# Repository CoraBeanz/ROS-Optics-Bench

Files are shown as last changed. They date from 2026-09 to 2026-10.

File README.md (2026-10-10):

<p align="center">
  Self-Aligning Laser-to-Fiber Bench. Seen from above, a 635 nm laser beam passes an aperture, two polarizers and a beamsplitter, folds off two motorized mirrors, M1 and M2, and is focused into a single-mode fiber. M1 gets knocked, the focused spot slides off the fiber's core and the coupling drops t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
</p>

<h3 align="center">A mostly 3D-printed optical bench that couples a 635 nm laser into an optical fiber by itself. Knock a mirror out of line and four stepper-driven adjusters steer the beam back to peak coupling, with no hands on the knobs.</h3>

<p align="center">
  
  
  
  
  
  
  
  
</p>

<p align="center">
  <a href="#how-it-works"><b>How it works</b></a> ·
  <a href="#the-bench"><b>The bench</b></a> ·
  <a href="#optical-path"><b>Optical path</b></a> ·
  <a href="#auto-align"><b>Auto-align</b></a> ·
  <a href="#electronics"><b>Electronics</b></a> ·
  <a href="#software"><b>Software</b></a> ·
  <a href="#roadmap"><b>Roadmap</b></a> ·
  <a href="docs/bom/README.md"><b>Parts list</b></a>
</p>

## How it works

Getting a laser into a single-mode fiber means landing a focused spot on a core a few microns across, at the right angle. By hand that takes two kinematic mirrors, four knobs and a lot of patience. Here a NEMA 8 stepper turns each knob, and two photodiodes tell the motors how close they are.

| 1 · Score the coupling | 2 · Find the light | 3 · Steer and walk |
|---|---|---|
| A beamsplitter sends part of the laser to a reference photodiode, and the fiber's output lands on a second one. Their ratio is the score, so laser flicker cancels out. | After a knock the spot has usually left the core and the output reads nothing. M2 steps the spot outward in a square spiral until the output photodiode sees light again. | M2 alone moves the spot across the core. M1 with a matched, opposite M2 move changes only the angle. Alternating the two climbs the long, thin peak that one-knob-at-a-time adjusting stalls on. |

## The bench

<p align="center">
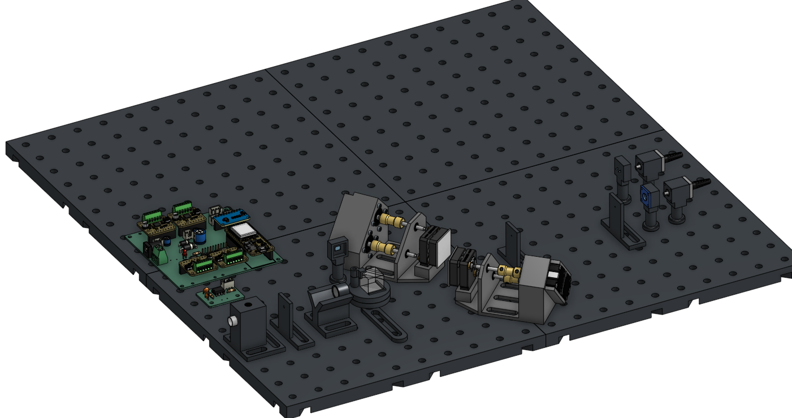
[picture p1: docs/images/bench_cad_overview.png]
Onshape render of the whole bench on four printed breadboard tiles: the control board at the back left, the laser, aperture, polarizer and beamsplitter in front, the two motor-mirror assemblies in the middle, and the lens and fiber mounts at the right.
  
</p>

<table>
  <tr>
    <td width="50%" valign="top">
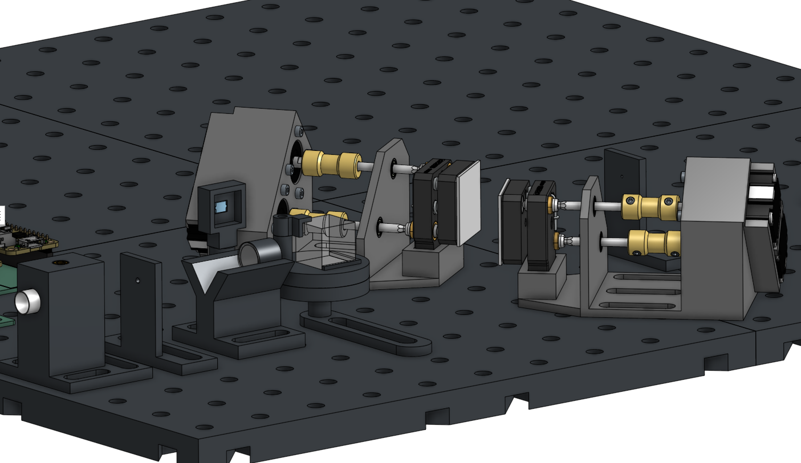
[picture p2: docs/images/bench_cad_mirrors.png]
Close-up render of the laser, polarizer and beamsplitter, then M1 and M2, each with two NEMA 8 motors turning its adjusters through brass couplers and hex rods.
      
      <br><sub>Laser, polarizer and beamsplitter, then M1 and M2, each with two NEMA 8 motors turning its adjusters through brass couplers and hex rods.</sub>
    </td>
    <td valign="top">

**Light.** A 635 nm Quarton laser module under 1 mW, trimmed by a 2 mm printed aperture and dimmed by two crossed polarizers.

**Steering.** Two 1 in mirrors in Thorlabs KMS-style kinematic mounts. A NEMA 8 stepper turns each 100 TPI adjuster through a brass coupler and a 2 mm hex rod: four motorized axes, 79 nm of screw travel per microstep.

**Focus.** An f = 8 mm asphere on a micrometer stage focuses the beam onto a fixed FC bulkhead. The lens moves; the fiber stays put.

**Sensing.** BPW34 photodiodes on MCP6002 transimpedance amps, read by a 16-bit ADS1115.

**Control.** An ESP32 Feather V2 drives four TMC2209s on one UART bus and takes plain-text commands over USB from a desktop test panel or from ROS 2 on a Jetson.

**Base.** Printed breadboard tiles on a 25 mm hole grid, so parts come off and go back in the same place.

  </td>
  </tr>
</table>

The full CAD model is one STEP file exported from Onshape with its subassembly tree, [`cad/assemblies/ros_laser_bench_main_assembly.step`](cad/assemblies/README.md). Every part to buy, print or check is in the [parts list](docs/bom/README.md) (source: `docs/bom/bom.csv`).

## Optical path

<p align="center">
  Top view of the optical path: laser, 2 mm aperture, crossed polarizers and beamsplitter along the bottom, with the reference photodiode on the beamsplitter's side port; M1 turns the beam up to M2, 150 mm away, which sends it along the top through two irises to the f = 8 mm asphere on its stage and 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
</p>

The beam folds in a Z. M1 and M2 sit 150 mm apart, and M2 is 310 mm from the lens, so tilting the two mirrors together can set both where the beam crosses the lens and the angle it arrives at, and through them where the focused spot lands on the fiber face and the angle it enters at. One microstep tilts a mirror by about 4.6 µrad. One turn of M2's X adjuster moves the spot about 230 µm across the fiber face, and one turn of its Y adjuster about 165 µm, because at a 45° fold a vertical tilt bends the beam by √2 times the tilt instead of twice it.

The 2 mm aperture does mode matching. The laser's 7 x 3 mm beam is much bigger than the single-mode fiber's mode seen at the lens (1.5 mm across), so only its centre can couple. In the bench twin 83% of the light through the aperture couples, against 25% of the whole beam without it. The fiber gets about a quarter of the laser's power either way, but with the aperture the light that could never couple is stopped before the beamsplitter, so the out/ref score at the peak is 0.67 instead of 0.20. In phase 1 the OV9281's bare sensor takes the lens's place, and with the two irises it lets the mirrors put the beam on the lens axis by spot position before the lens and fiber go in.

## Auto-align

<p align="center">
  Coupling over M1X and M2X computed by the bench twin: a long, thin, bright ridge running diagonally. After M1 is knocked 1.2 mrad, a square spiral on M2 finds the light on the ridge, then the steer-and-walk path follows the ridge to 99% of the best, while one motor at a time stalls part-way along i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
</p>

With a single-mode fiber the coupling depends on where the spot lands on the core (set by the beam's angle at the lens) and on the angle it comes in at (set by the beam's offset at the lens). The first is about 25 times more sensitive, and both mirrors change both, so in motor coordinates the peak is a ridge 23 times longer than it is wide, running diagonally across M1 and M2. Turning one knob at a time crawls along it. Auto-align, in the [test panel](#bench-test-panel) and as a [ROS 2 action](#ros-2-on-the-jetson), uses the two moves people use by hand instead:

- **Find.** If the output photodiode sees nothing, M2 steps the spot outward in a square spiral, up to **Search (turns)** either way, until the out/ref ratio clears 2% of its aligned value.
- **Steer.** M2 alone moves the spot across the core: the narrow direction, 25 microsteps to the 1/e point on M2X.
- **Walk.** M1 plus a matched, opposite M2 move keeps the spot where it is and changes only the angle: the wide direction, about 580 microsteps of M1.
- **Repeat** walk and steer on both planes until a sweep gains less than 0.3%. Each line search approaches its points from the same side, so the play in the hex couplings always sits the same way.

The first run on a fiber also measures the walk directions on the real bench, since they depend on motor directions and lever arms. In 100 simulated knocks of 0.3 to 3 mrad, steer and walk brought all 100 back above 99.9% of the best coupling, with a median of 19 s and a worst case of 66 s. One motor at a time got 59 back to 90%. Everything here comes from the [bench twin](#bench-twin-simulator); Auto-align hasn't run on the hardware yet.

## Electronics

| Part | Role |
| --- | --- |
| Adafruit ESP32 Feather V2 | Real-time side: steppers, soft limits, photodiode sampling, laser |
| 4x Adafruit TMC2209 breakout on one UART bus | Stepper drivers: 3200 microsteps per adjuster turn, StealthChop, current set over UART |
| ADS1115 (16-bit ADC) + 2x BPW34 photodiode on an MCP6002 transimpedance amp (47 kΩ) | Reference and output power |
| 12 V supply | Motor power; the Feather runs from USB |
| Jetson (ROS 2) | Camera, optimizer, experiment control |
| Arducam OV9281 (global shutter, UVC) | Bare-sensor beam profiler for phase 1 |

<table>
  <tr>
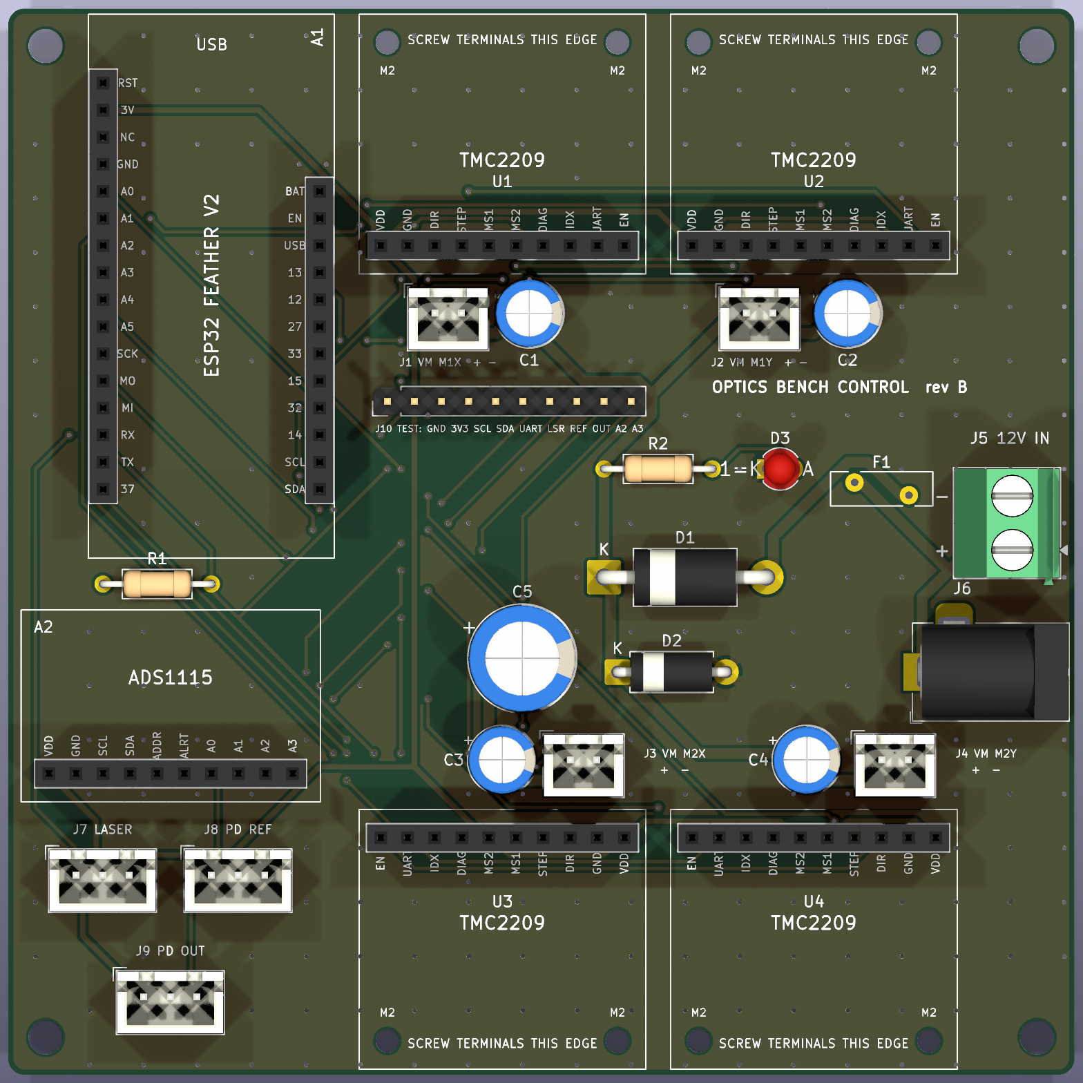
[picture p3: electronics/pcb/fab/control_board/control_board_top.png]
Top render of the control board: sockets for the ESP32 Feather V2, four TMC2209 breakouts with their screw-terminal edges facing out, and the ADS1115; the 12 V input with fuse, diodes and bulk capacitor; JST-XH plugs for the drivers, laser and both photodiodes; and a 10-pin test header.
    <td width="58%"></td>
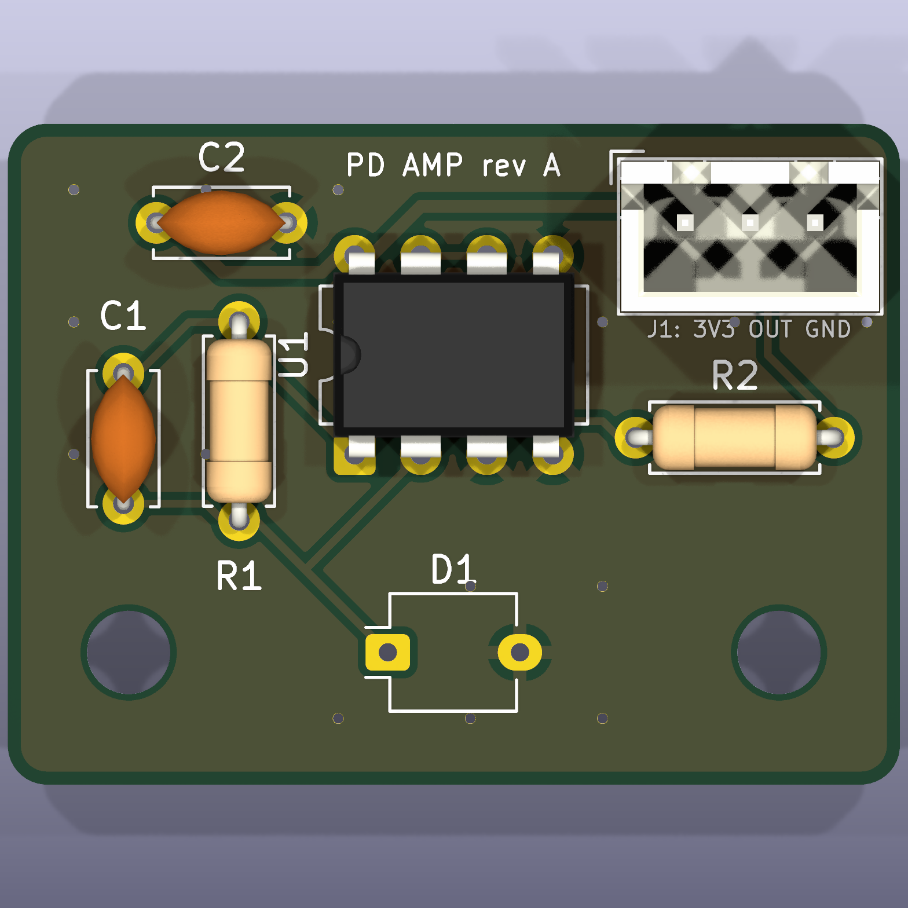
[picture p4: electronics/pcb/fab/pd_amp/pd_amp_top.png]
Top render of the photodiode amp board: the BPW34 footprint, the MCP6002 op-amp, the feedback resistor and capacitor, and a 3-pin JST-XH plug.
    <td width="42%"></td>
  </tr>
  <tr>
    <td><sub>Control board, 100 x 100 mm, two layers. The Feather, the four TMC2209 breakouts and the ADS1115 plug in.</sub></td>
    <td><sub>Photodiode amp, 34 x 25 mm. Build two: reference and output.</sub></td>
  </tr>
</table>

Both boards are KiCad 10 projects generated from Python, all through-hole, with Gerbers ready to order in [electronics/pcb](electronics/pcb/README.md). Every cable on the bench is in [electronics/system_wiring.svg](electronics/system_wiring.svg), and the full pin table is in [electronics/wiring.md](electronics/wiring.md).

## Software

<p align="center">
  Block diagram of the code. The ESP32 firmware drives the four motor drivers, the laser and the ADS1115, and talks plain text over USB serial. bench_link connects either the real ESP32 or the bench twin simulator to two front ends, the PySide6 test panel and the ROS 2 packages on the Jetson, which b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
</p>

Where each piece lives, and how far it has been run:

| Module | What it does | Run so far |
| --- | --- | --- |
| [`firmware/optics_bench`](#building-the-firmware) | Arduino IDE sketch for the ESP32: four axes with soft limits and positions kept in flash, auto-ranging photodiode sampling, the laser, and the serial protocol | On the bench: laser, all four motors and both photodiodes |
| [`tools/test_gui.py`](#bench-test-panel) | Dark-mode PySide6 test panel: jog, go-to, photodiode readout and plots, CSV logging and Auto-align; `--sim` runs it on the bench twin | On the bench; Auto-align on the simulator only |
| [`tools/bench_twin`](#bench-twin-simulator) | Physical model of the bench and the Aligner both front ends run; `tools/twin.py` runs trials and draws figures | 14 unit tests |
| [`host/ros2_ws`](#ros-2-on-the-jetson) | ROS 2 Humble packages for the Jetson: the bench as topics, services and actions, Align as an action, and a beam-spot node for the OV9281 | Against the simulator on Humble |

### Building the firmware

1. In the Arduino IDE, install the ESP32 boards package (Boards Manager, "esp32" by Espressif).
2. Install the libraries below with the Library Manager.
3. Open `firmware/optics_bench/optics_bench.ino`.
4. Select your ESP32 board and port, then Upload. Serial Monitor runs at 115200 baud with newline line endings.

Code in `src/` is compiled with the sketch automatically. Record any library added through the Library Manager here so the build can be reproduced.

| Library | Version | Used for |
| --- | --- | --- |
| TMCStepper (teemuatlut) | 0.7.3 | TMC2209 register setup over UART |
| AccelStepper (Mike McCauley) | 1.64 | Ramped STEP/DIR motion |
| Adafruit ADS1X15 | 2.6.2 | ADS1115 photodiode ADC over I2C (pulls in Adafruit BusIO) |

The firmware was last built with the esp32 boards package 3.3.7.

Every pin is set in `firmware/optics_bench/config.h`. The wiring diagram and full pin table for the Feather ESP32 V2, the four Adafruit TMC2209 breakouts, the laser, the ADS1115 and the two photodiode amplifier boards are in [electronics/wiring.md](electronics/wiring.md). The serial protocol is plain text and documented in `firmware/optics_bench/src/comms/protocol.h`, so the Serial Monitor or the Jetson can use the same commands.

### Bench test panel

<p align="center">
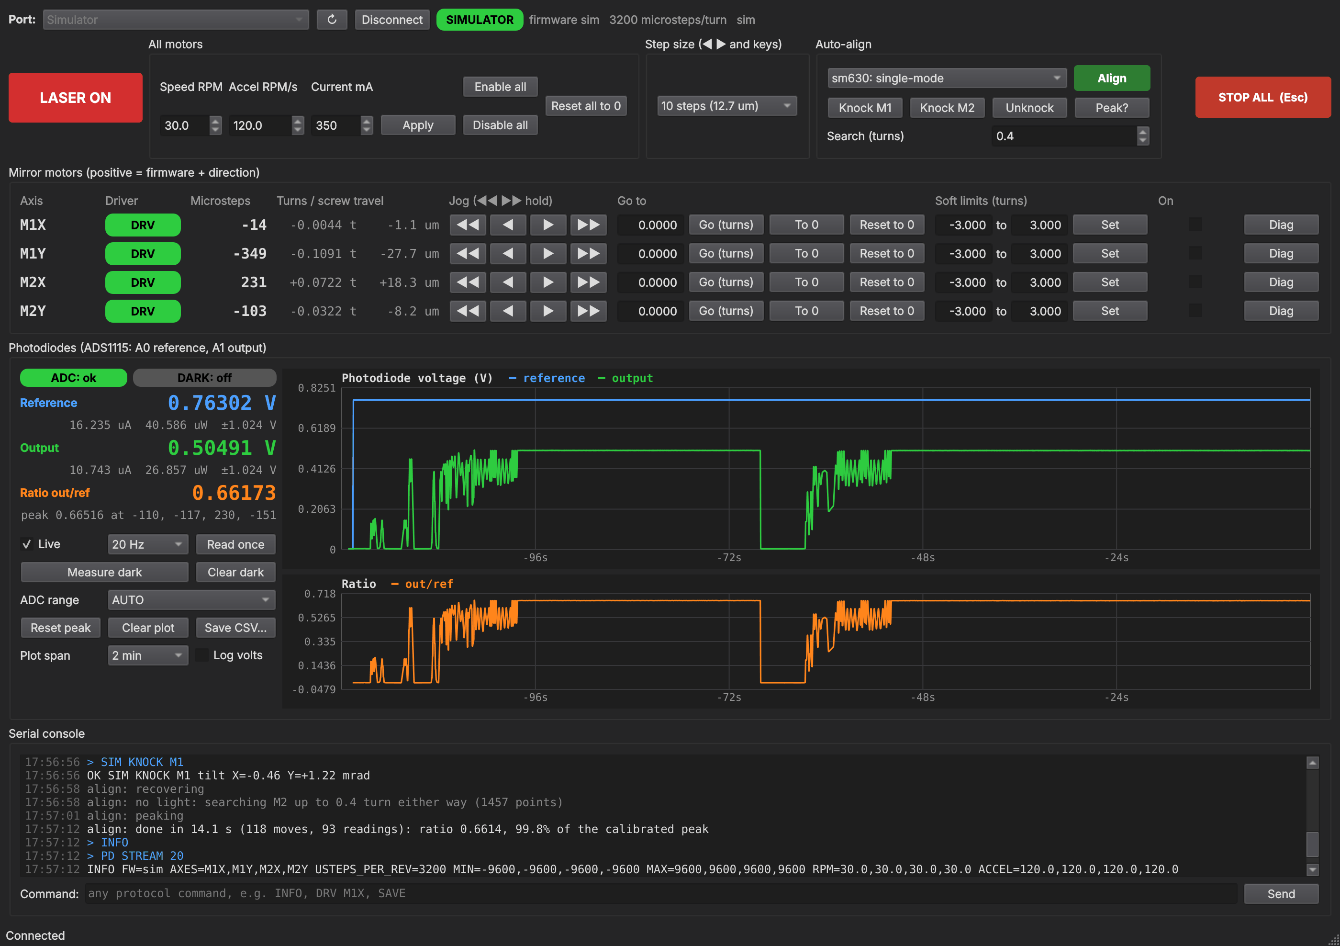
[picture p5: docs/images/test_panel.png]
The test panel connected to the simulator after a knock and an automatic recovery: the four motor rows, the photodiode readout, and plots of the reference and output voltages and their ratio dropping at the knock and climbing back.
  
</p>

`tools/test_gui.py` is a small desktop app for the bench tests: laser on/off, jog, nudge and go-to for the four mirror motors, and live photodiode readings. It is a dark-mode Qt window built on PySide6 (the LGPL Qt binding) and pyserial, both listed in `tools/requirements.txt`.

```
py -3 -m pip install -r tools/requirements.txt
py -3 tools/test_gui.py          # pick the ESP32's COM port, Connect
py -3 tools/test_gui.py --sim    # try it without hardware
```

`py -3` picks the regular Python install on Windows; a bare `python` can resolve to another bundled interpreter such as KiCad's.

- **Positions** are in microsteps, 3200 per adjuster turn. One turn of a 100 TPI adjuster is 254 um, so a full step is about 1.3 um of screw travel.
- **Zero and soft limits.** "Reset to 0" on a motor's row calls its current knob position zero without moving it, and "Reset all to 0" does all four. Use them whenever the stored position has stopped matching reality, for example after turning an adjuster by hand. The soft limits (default -3 to +3 turns, adjustable up to +-8) stay relative to zero, because the hex bit only has about 4 turns of engagement one way. Positions and limits are saved to flash and survive a power cycle. If power drops mid-move, the panel warns that positions may be off until you press "Reset all to 0" (zeroing the motors one at a time doesn't clear it).
- **Coil release.** A motor is powered only while it moves: it is released 0.5 s after it stops, so the motors stay cool between moves, and the non-back-driving adjuster screws hold the mirror. The **On** box shows whether a motor is powered; ticking it holds that motor powered until you untick it. `AUTO_RELEASE` in `config.h` turns this off.
- **Hold-to-jog** (the double arrows) keeps a motor running while the button is held. The firmware stops it by itself if the panel stops refreshing the jog, so a crashed GUI can't run a motor to its limit.
- **Keys:** arrows move M1 (Left/Right = M1X, Down/Up = M1Y), A/D and S/W move M2X and M2Y by the selected step, L toggles the laser, Esc stops everything.
- **Diag** shows the TMC2209 status (current, StealthChop, overtemperature, short and open-load flags). A driver that doesn't answer on the UART shows a red dot and refuses to move.
- **Auto-align.** Pick the fiber on the bench and press **Align**. It finds the light, then peaks the out/ref ratio by steering with M2 and walking M1 and M2 together (see [Auto-align](#auto-align)). The first run after connecting or switching fiber also measures the walk directions, so start it near the peak; the panel keeps them until it disconnects. Later runs recover from wherever the beam is, for example after a knock. If there is no light on the output photodiode, it first searches with M2 up to **Search (turns)** either way (default 0.4 turn: about ±90 µm across the fiber face and ±65 µm up and down; one turn of M2X moves the spot about 230 µm, one turn of M2Y about 165 µm). The search covers a square, so its time grows with the square of that number, and the log says how many points it will visit. Soft limits still stop any move that would pass them. **Stop** or Esc ends it. It uses the same serial commands as the rest of the panel, but it has only been run against the simulator so far.
- **Photodiodes.** Tick **Live** to stream the reference and output photodiode voltages (5 to 50 readings a second, each the average of all ADC samples since the last one). The panel shows each voltage with its photocurrent and optical power, the output/reference ratio with the best ratio seen and the motor positions where it happened, and a rolling plot (log scale optional). **Measure dark** switches the laser off briefly, records the offsets and subtracts them from then on. **ADC range** fixes the ADS1115 gain instead of auto-ranging, and **Save CSV** writes up to the last 30,000 readings (10 minutes at 50 a second).
- **Simulator.** `--sim` (or the Simulator port) runs the bench twin behind the same serial commands: the photodiodes read what the modelled optics couple into the chosen fiber, with the best position hidden a little way from zero. **Knock M1** and **Knock M2** tilt a mirror by 0.5 to 2 mrad as if bumped, **Unknock** takes the knocks out, and **Peak?** shows where the best position is. Knock, then Align, to watch it recover. The same commands work from the console as `SIM KNOCK M1 [mrad]`, `SIM PEAK`, `SIM FIBER sm630` and `SIM RESET`.

#### First power-up checklist

1. Flash the firmware and connect. A driver whose 12 V supply is off doesn't answer on the UART, so it shows a red dot, and a move on that axis is refused with "driver offline".
2. With the 12 V supply on, send `REPROBE ALL` (or just move the axis, which retries). The dots should go green, and the REPROBE reply should end in `slots=ok` (the connection bar picks it up on the next `INFO`).
3. Take the hex bits out of the adjusters and nudge each motor by 1/4 turn to check which way positive turns. Flip it with `invert` in `config.h` if needed.
4. Refit the bits, press "Reset all to 0", and start aligning.
5. With the ADS1115 and photodiode boards connected, the photodiode panel should show `ADC: ok`. Cover each diode and shine a light on it to check its channel, then press **Measure dark** with the room lit as it will be during runs.

### Bench twin (simulator)

`tools/bench_twin` is a small physical model of the bench, used to size and test the alignment routine before the hardware can. It models:

- **Optics:** the 7 x 3 mm laser beam cut by the 2 mm aperture, the two mirrors 150 mm apart, iris 2 at 3 mm, and the f = 8 mm lens. Single-mode coupling is the overlap of the laser field with the fiber mode, including the aperture's hard edge. Multimode coupling is the share of the focused spot that the core accepts.
- **Motors:** 100 TPI adjusters on a 17.3 mm lever and a little play in each hex coupling. The randomized benches the simulator and the trials use also add a little crosstalk between each mount's two axes.
- **Photodiodes:** the reference and output photodiodes through the ADS1115, with noise and dark offsets.
- **Knocks:** a bumped mirror mount tilts by an amount the motors don't know about.

```
py -3 tools/twin.py                       key numbers (--fiber sm630, mm50 or smf28)
py -3 tools/twin.py ceiling               best coupling vs aperture size and lens focal length
py -3 tools/twin.py trials -n 100 --compare   knock a mirror and recover, 100 times, both methods
py -3 tools/twin.py landscape             redraws docs/images/twin_landscape.png (needs matplotlib)
py -3 -m unittest discover tools/tests
```

What it says so far, for the single-mode fiber:

- **The peak is narrow and diagonal.** Moving M2X alone, coupling falls to 1/e within 25 microsteps (1.5 full steps). Moving M1 and M2 together the opposite way ("walking"), it stays up for about 580 microsteps. So in motor coordinates the peak is a long, thin ridge, 23 times longer than it is wide, running diagonally across M1 and M2. Adjusting one motor at a time stalls part-way along it.
- **Recovery.** In 100 simulated knocks of 0.3 to 3 mrad on a random mirror, steer and walk got all 100 back above 99.9% of the best coupling, with a median of 19 s and a worst case of 66 s (at 60 RPM and 600 RPM/s). One motor at a time got 59 of 100 back to 90%, and its worst case ended at 41%. Most of the time goes into finding the light again. Knocks of M1 above about 5 mrad can defeat the search even though M2 could still put the spot back on the core: the beam then crosses the lens about 1.5 mm off axis and enters the fiber too steeply, so M2 alone brings back under 3% of the peak and the spiral never sees light (7 of the 48 M1 knocks in a run of 100 knocks of 3 to 6 mrad). A larger **Search (turns)** doesn't help these.
- **The 2 mm aperture is close to ideal for coupling efficiency.** With the f = 8 mm lens, 83% of the light that gets through it can be coupled. The best combination tried reaches 86% (a 2.5 mm aperture with f = 11 mm), and 2 mm with f = 9 mm gets 85%. Without the aperture only 25% couples, because the 7 x 3 mm beam is much bigger than the fiber mode seen at the lens (1.5 mm). The aperture passes only 30% of the beam, so the fiber gets about a quarter of the laser's power either way; what it changes is the out/ref ratio at the peak, 0.67 instead of 0.20, since the reference photodiode sits after it.
- **The play in the hex couplings matters.** One degree of play is about 9 microsteps, a third of the single-mode peak's width. Each line search in the routine therefore approaches its points from one side.

The numbers rest on estimates to replace with bench measurements, all set in `tools/bench_twin/bench.py` and `optics.py`:

| Estimate | Value used | How to measure |
| --- | --- | --- |
| Adjuster lever arm | 17.3 mm (from the 24.5 mm motor spacing) | Scan M2X across the peak; the width scales with it |
| Play per hex coupling | 1 degree (9 microsteps) | Hysteresis test: approach the same point from both sides |
| Laser beam | 7 x 3 mm across (taken as the 1/e^2 width) | Camera or knife edge |
| Fiber mode | 4.2 um across (630HP) | Datasheet |
| Lens clear aperture | 5 mm | The lens listing |
| Beamsplitter, laser power, polarizer setting | 50/50, 0.9 mW, 30% | Photodiode volts |

The banner at the top of this page replays one of these runs: M1 knocked 1.5 mrad on the single-mode fiber, recovered in 17 s. The figures are drawn by the scripts in [`docs/images/src`](docs/images/src/common.py); the banner and the Auto-align figure run the twin to get their numbers.

### ROS 2 on the Jetson

`host/ros2_ws` holds ROS 2 Humble packages for the Jetson: a driver node that puts the ESP32 (or the simulator) on ROS topics, services and actions, with Align as an action; a node that finds the laser spot on the OV9281; and launch files. They use `tools/bench_link.py` and `tools/bench_twin` directly, so they align the same way the test panel does. Setup and usage: [host/ros2_ws/README.md](host/ros2_ws/README.md).

```
ros2 launch optics_bench_bringup bench.launch.py                          # on the simulator
ros2 launch optics_bench_bringup bench.launch.py port:=/dev/optics_bench  # on the bench
```

## Roadmap

The laser, all four mirror motors and both photodiodes (on hand-wired amplifiers for now) work on the bench, and first fiber coupling by hand is under way. The PCBs are designed but not ordered yet. Auto-align and the ROS 2 packages have run only against the bench twin so far, and the ROS 2 packages haven't run on the Jetson, the ESP32 or the camera yet.

- [x] Bench CAD in Onshape: printed base, motor-mirror assemblies, optics mounts ([`cad/`](cad/assemblies/README.md))
- [x] Firmware for the laser, the four mirror motors and both photodiodes, and the [test panel](#bench-test-panel), running on the bench
- [x] [Bench twin](#bench-twin-simulator) and Auto-align, tested in simulation over hundreds of knocks
- [x] [ROS 2 Humble packages](#ros-2-on-the-jetson), run against the simulator
- [x] Control board and photodiode amp PCBs designed, with Gerbers ready ([`electronics/pcb`](electronics/pcb/README.md))
- [ ] **Phase 1, beam steering:** the camera and the two irises put the beam on a known axis by spot position
- [ ] **Phase 2, fiber coupling:** swap the camera for the lens and fiber and climb to maximum coupled power, multimode first, then single-mode
- [ ] **Phase 3, the demo:** bump a mirror and watch it recover on the real bench
- [ ] PCBs ordered and built, and ROS 2 running on the Jetson

## Stack

| Layer | Built with |
|---|---|
| **Optics** | 635 nm diode laser, 2 mm aperture, crossed polarizers, 1 in mirrors in kinematic mounts, f = 8 mm asphere, FC fiber |
| **Mechanics** | 3D-printed mounts and base designed in Onshape; NEMA 8 steppers, brass couplers and hex rods on 100 TPI adjusters |
| **Electronics** | ESP32 Feather V2, TMC2209 drivers, ADS1115 and BPW34 photodiodes on MCP6002 amps; KiCad 10 boards generated from Python |
| **Firmware** | C++ Arduino IDE sketch on the ESP32: TMCStepper, AccelStepper, plain-text serial protocol |
| **Desktop** | Python, PySide6 and pyserial: the dark-mode test panel |
| **Simulation** | Python and numpy: Gaussian-beam coupling, motors with play, photodiodes, and the Aligner |
| **Robotics** | ROS 2 Humble on a Jetson: driver node with Align and MoveTo actions, v4l2_camera and a beam-spot node |

## Repository layout

```
cad/
├── assemblies/            the whole bench as one STEP from Onshape, and its README
├── parts/pcb/             STEP models and 3D renders of the two PCBs
└── print/, vendor/        placeholders for print-ready files and purchased-part models
docs/
├── bom/                   parts list: bom.csv, and the README tools/make_bom_md.py generates from it
└── images/                README figures; images/src/ holds the scripts that draw the SVGs
electronics/
├── wiring.md, wiring.svg  pin table and wiring diagram for the Feather, drivers, laser, ADC and amps
├── system_wiring.svg      every cable on the bench
└── pcb/                   KiCad projects (control board, photodiode amp), their generator and fab outputs
firmware/optics_bench/     Arduino IDE sketch for the ESP32
├── optics_bench.ino       setup() and loop()
├── config.h               pin map, bus addresses, motor limits
└── src/                   motion (drivers, soft limits), sensing (ADS1115), laser, comms (protocol)
host/ros2_ws/              ROS 2 Humble workspace for the Jetson: driver, camera, interfaces, bringup
tools/
├── test_gui.py            the bench test panel
├── bench_link.py          serial and simulator links to the controller, shared by the panel and ROS
├── bench_twin/            the bench simulator and the Aligner
├── twin.py                trials, coupling ceiling, landscape figure
├── tests/                 unit tests for the twin and the Aligner
└── make_bom_md.py         writes docs/bom/README.md from bom.csv
```

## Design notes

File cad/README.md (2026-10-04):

# CAD

Mechanical design lives in Onshape. This folder holds STEP exports so the repo has a snapshot of the hardware that matches the code.

- `assemblies/`: full assemblies, starting with the whole bench in `ros_laser_bench_main_assembly.step` (see [assemblies/README.md](assemblies/README.md))
- `parts/`: single parts, printed or machined, and the PCB models in `parts/pcb`
- `print/`: STL or 3MF files ready to slice
- `vendor/`: models of purchased parts (NEMA 8 motors, mirror mounts, lens tubes)

Re-export and commit a STEP file whenever the Onshape model changes in a way the firmware or bench notes depend on, and say what changed in the commit message.

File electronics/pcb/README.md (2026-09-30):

# Circuit boards

Two KiCad 10 projects replace the perfboard wiring:

| Board | Size | What it does |
| --- | --- | --- |
| [control_board](control_board) | 100 x 100 mm, 2 layers | Carrier for the ESP32 Feather V2, the four TMC2209 breakouts and the ADS1115. Adds the 12 V input protection, a VM feed for each driver, laser and photodiode plugs, and a test header for the Analog Discovery 3. |
| [pd_amp](pd_amp) | 34.3 x 25.4 mm, 2 layers | Photodiode amplifier: BPW34 into an MCP6002 transimpedance amp. Build two, one for the reference diode and one for the fiber output. |

Control board

How it all connects: [../system_wiring.svg](../system_wiring.svg) and [../wiring.md](../wiring.md).

## Why a carrier board and not chip-down parts

The Feather, the TMC2209 breakouts and the ADS1115 plug into female headers. The TMC2209 breakouts keep their screw terminals: each one plugs in by its 10-pin logic header only, with the terminals along the board's top or bottom edge and the wire entries facing out. The carrier board itself only has through-hole parts that cost a few dollars in total, and it fits the cheapest price tier at JLCPCB and PCBWay (100 x 100 mm, 2 layers).

- The breakouts are already on hand, and this firmware already runs on them.
- A chip-down TMC2209 is a QFN-28 with a thermal pad. It needs fab assembly and its own layout checks (sense resistors, charge pump, thermal vias), and a board with an ESP32 module would need the USB and boot circuits too. That is a second board bring-up for no gain on a four-motor bench.
- A failed driver or Feather is swapped by unplugging it.
- Every pin matches `firmware/optics_bench/config.h`, so the firmware doesn't change.

## Ordering

Upload `fab/<board>/<board>_gerbers.zip` as-is. Defaults are fine: 2 layers, 1.6 mm FR-4, 1 oz copper, HASL, any mask colour. The zip holds the copper, mask, silkscreen, outline and one Excellon drill file. There are no SMD parts, so no stencil or assembly files are needed.

Parts: `fab/<board>/<board>_bom.csv`. All the parts are through-hole and stocked at DigiKey, Mouser and LCSC. The part numbers are suggestions, and any part with the same footprint fits.

## Assembly notes (control board)

1. Solder the low parts first: R1, R2, D1-D3, F1, then J10, the JST-XH plugs, J5, J6 and the capacitors (mind the + marks).
2. Solder the female headers for A1 (16 + 12 pins), U1-U4 (10 pins each) and A2 (10 pins). Plug the boards in while soldering so the headers stay straight.
3. The TMC2209 breakouts keep their screw terminals. Each one plugs in by its logic header, with the terminal edge at the board edge. Two M2 x 11 mm standoffs under the terminal-end mounting holes (marked M2 on the board) hold that end up while you tighten the screws. Check the standoff height against your header stack (about 8.5 mm socket plus the 2.5 mm plastic of the male header).
4. Wire each motor straight into its breakout's 1A/1B/2A/2B terminals. Run a 2-wire lead from the carrier's VM plug next to the driver (J1-J4, pin 1 = +12 V, pin 2 = GND, marked + -) into the breakout's VM + and GND terminals.
5. The UART addresses are set by the board: U1 = 0 (M1X), U2 = 1 (M1Y), U3 = 2 (M2X), U4 = 3 (M2Y). Put each breakout in its own slot.
6. Before plugging anything in, power J5 or J6 with 12 V and check that D3 lights, that J1-J4 read about 11.5 V (after the Schottky), and that 3V3 isn't shorted to GND.

## Connectors

Control board:

| Ref | Type | Pins |
| --- | --- | --- |
| J1-J4 | JST-XH 2 | VM feed for the M1X, M1Y, M2X and M2Y breakouts: 1 = +12 V, 2 = GND. A short lead goes to the breakout's VM + / GND screw terminals |
| U1-U4 terminals | Breakout screw terminals, 2.54 mm | Motor coils: 1A/1B = coil A, 2A/2B = coil B, plus VM + / GND from J1-J4 |
| J5 | Screw terminal, 5.08 mm | 12 V in: + and - (marked) |
| J6 | Barrel jack 5.5 x 2.1 mm | 12 V in, centre positive (same net as J5, so use one of them) |
| J7 | JST-XH 3 | Laser: 1 = 3V3, 2 = TTL (GPIO 21), 3 = GND |
| J8 | JST-XH 3 | Reference photodiode board: 1 = 3V3, 2 = PD_REF (ADS1115 A0), 3 = GND |
| J9 | JST-XH 3 | Output photodiode board: 1 = 3V3, 2 = PD_OUT (ADS1115 A1), 3 = GND |
| J10 | 1x10 pin header | Test: 1 GND, 2 3V3, 3 SCL, 4 SDA, 5 UART bus, 6 LASER TTL, 7 PD_REF, 8 PD_OUT, 9 ADS1115 A2, 10 A3 |
| A1 | Feather V2 socket | USB-C faces the top edge |

Photodiode board: J1 (JST-XH 3) is 1 = 3V3, 2 = VOUT, 3 = GND, which matches J8 and J9, so the cable is wired 1:1.

## Design notes

- **12 V input.** A 2 A PTC fuse (F1), a 1N5822 Schottky in series for reverse polarity (about 0.4 V drop), an 18 V bidirectional TVS (D2), 470 uF bulk capacitance, and 100 uF at each driver's VM plug, on top of the breakout's own 22 uF. The motor current is well under 1 A in total at 350 mA RMS per motor.
- **Ground.** Both layers are ground pours, stitched with vias. The photodiode signal returns through the pour straight back to the ADS1115.
- **DIAG.** Each driver's DIAG output goes to an input-only Feather pin (M1X to I34/A2, M1Y to I39/A3, M2X to I36/A4, M2Y to I37). The firmware doesn't read them yet, so they're there for stall detection later. INDEX isn't connected.
- **Tracks.** Signals are 0.3 mm, 3V3 is 0.5 mm and 12 V is 1.0 mm, and a 0.4 mm ground tree runs under the pours. Motor current never crosses the carrier: it goes from the breakout's terminals straight to the motor. The clearance is 0.2 mm, or 0.3 mm on 12 V. Every rule is in the `.kicad_pro` files.
- **Mounting.** The control board has an M3 hole in each corner, 93 mm apart, which doesn't land on the bench's 25 mm insert grid, so it needs a printed plate or standoffs. The photodiode board has two M3 holes 25 mm apart, centred on the BPW34, so it bolts straight onto the grid.

## Regenerating

The schematics and boards are generated from `gen/design.py`, which is the only place parts, pins and positions are defined. After editing it:

```
py -3 electronics/pcb/gen/build.py
```

The generators look for KiCad in `C:/Users/Vince/AppData/Local/Programs/KiCad/10.0`. To use another install, set `KICAD_DIR`.

That runs, in order:

1. `make_lib.py`: the custom symbols and socket footprints in `lib/`.
2. `make_sch.py`: the schematics.
3. `kicad-cli`: the netlist.
4. `make_pcb.py` (KiCad's Python): placement, routing and ground pours.
5. ERC, and DRC with schematic parity.
6. The fab outputs in `fab/`.

It stops with an error if ERC or DRC finds anything or a net is left unrouted. The router is a small A* grid router in `gen/route.py`.

To open a board in KiCad and edit it by hand, open `control_board/control_board.kicad_pro`. A rerun of `build.py` overwrites manual edits, so once the board is being edited by hand, stop regenerating it.

## Open assumptions

- The breakout's screw terminals take wires from the breakout's outer edge, so with the terminal edge on the board edge the wires come in from outside the board. Check the direction on one breakout. If the entries face the other way, swap each pair of driver slots in `gen/design.py`.
- The M2 standoff holes sit under the breakout's terminal-end mounting holes, taken from Adafruit's board file.
- The ADS1115 is the Adafruit 1085 layout (one 10-pin header, board above it). The newer STEMMA QT version has the same header order.
- The Jetson is the USB host for the Feather and the camera.

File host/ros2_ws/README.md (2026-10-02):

# ROS 2 workspace (Jetson)

ROS 2 Humble packages that run the bench from the Jetson. The ESP32 keeps the real-time work (stepping, soft limits, photodiode sampling); the Jetson talks to it over USB serial with the same text protocol as `tools/test_gui.py`, and adds the camera and the alignment routine.

| Package | What it does |
| --- | --- |
| `optics_bench_interfaces` | Messages, services and actions below |
| `optics_bench_driver` | `bench_driver` node: the ESP32 (or the simulator) as ROS topics, services and actions, including auto-align |
| `optics_bench_camera` | `beam_spot` node: where the laser spot is on the OV9281, for phase 1 |
| `optics_bench_bringup` | Launch files, parameters and a udev rule for the Feather |

The driver doesn't copy the bench code: it imports `tools/bench_link.py` (serial and simulator links) and `tools/bench_twin` (the auto-align routine and the simulator) from this repo, so the GUI and ROS always run the same alignment. Build the workspace where it is, inside the repo.

## Setting up the Jetson

JetPack 6 is Ubuntu 22.04, which is what ROS 2 Humble targets. (JetPack 5 is Ubuntu 20.04, which Humble doesn't support from apt; ask before going that way.)

1. Install ROS 2 Humble (`ros-humble-ros-base` is enough) by following the [Humble install guide](https://docs.ros.org/en/humble/Installation/Ubuntu-Install-Debs.html), then:
   ```
   sudo apt install python3-colcon-common-extensions python3-rosdep ros-humble-v4l2-camera python3-serial python3-numpy
   sudo rosdep init && rosdep update      # once
   ```
2. Let your user open the serial port and give the Feather a fixed name:
   ```
   sudo usermod -aG dialout $USER        # log out and back in
   sudo cp host/ros2_ws/src/optics_bench_bringup/udev/99-optics-bench.rules /etc/udev/rules.d/
   sudo udevadm control --reload && sudo udevadm trigger
   ```
   The Feather then shows up as `/dev/optics_bench`.
3. Build:
   ```
   cd host/ros2_ws
   source /opt/ros/humble/setup.bash
   rosdep install --from-paths src --ignore-src -y
   colcon build --symlink-install
   source install/setup.bash
   ```

## Running

```
ros2 launch optics_bench_bringup bench.launch.py                          # the simulator (bench twin)
ros2 launch optics_bench_bringup bench.launch.py port:=/dev/optics_bench  # the ESP32
ros2 launch optics_bench_bringup bench.launch.py port:=/dev/optics_bench camera:=true
```

Everything is under `/bench`:

| Name | Type | |
| --- | --- | --- |
| `/bench/status` | topic, `BenchStatus` | motor positions and targets, laser, coils, drivers (5 Hz) |
| `/bench/photodiodes` | topic, `Photodiodes` | reference and output volts and the out/ref ratio (10 Hz, more often while aligning) |
| `/bench/rx` | topic, `std_msgs/String` | every line the ESP32 sends |
| `/bench/command` | service, `Command` | any protocol line, e.g. `ZERO ALL`, `PD RANGE AUTO`, `SIM KNOCK M1 1` |
| `/bench/laser` | service, `std_srvs/SetBool` | laser on or off |
| `/bench/stop` | service, `std_srvs/Trigger` | stops every motor and any alignment |
| `/bench/pd_dark` | service, `std_srvs/Trigger` | measure and subtract the photodiode dark offsets |
| `/bench/move_to` | action, `MoveTo` | absolute or relative moves in microsteps |
| `/bench/align` | action, `Align` | find the light and peak the ratio |

Try it on the simulator:

```
ros2 service call /bench/laser std_srvs/srv/SetBool "{data: true}"
ros2 action send_goal /bench/move_to optics_bench_interfaces/action/MoveTo "{axes: [M2X], position: [300]}"
ros2 action send_goal --feedback /bench/align optics_bench_interfaces/action/Align "{fiber: mm50}"
ros2 service call /bench/command optics_bench_interfaces/srv/Command "{line: 'SIM KNOCK M2 1.5'}"
ros2 action send_goal /bench/align optics_bench_interfaces/action/Align "{}"
ros2 topic echo /bench/photodiodes
```

The first Align for a fiber finds light, measures the walk directions and records the peak ratio; that calibration is saved to `~/.ros/optics_bench/align_calibration.json`, so after a restart Align goes straight to recovering. Set `recalibrate: true` in the goal after changing the optics. While Align runs, the other services refuse to move anything; `/bench/stop` or cancelling the goal ends it.

## Camera

`beam_spot` takes `/camera/image_raw` from `v4l2_camera` and publishes `/camera/beam_spot` (`BeamSpot`): the spot's centroid and widths in pixels, its peak brightness, and whether it is saturated. Its settings and the camera's are in `optics_bench_bringup/config/camera.yaml`. It has only been run on synthetic frames so far. With the OV9281 plugged in, check what it offers with `v4l2-ctl --list-formats-ext -d /dev/video0` and set `image_size` and `pixel_format` to match.

## Tests

```
colcon test && colcon test-result --verbose
```

They run the driver against the simulator through its services and actions (about a minute), and the spot finder on synthetic frames. `tools/tests` covers the bench twin and the aligner on their own.

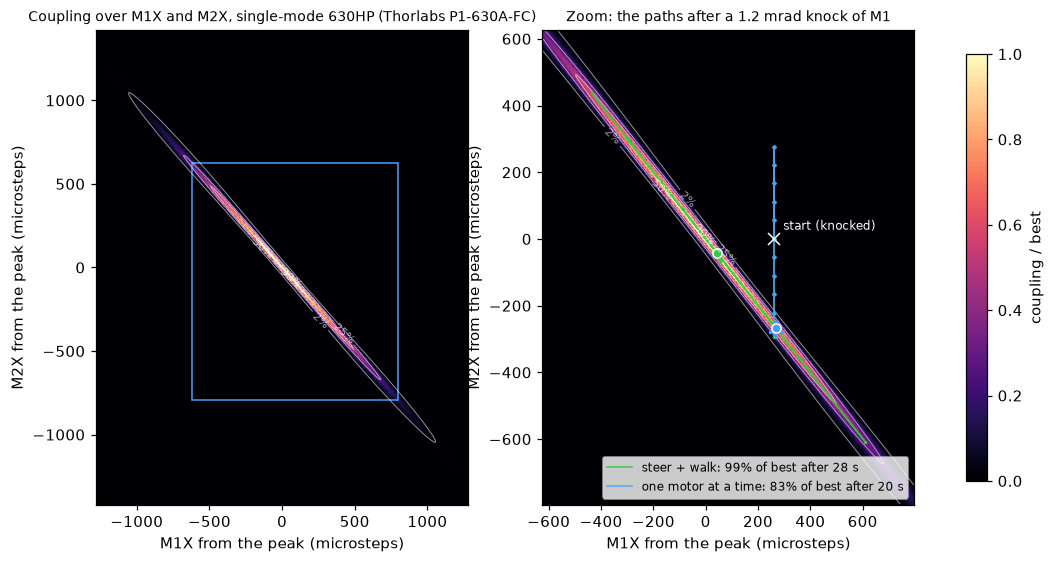
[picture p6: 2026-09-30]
docs/images/twin_landscape.png

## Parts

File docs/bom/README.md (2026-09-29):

# Bill of materials

Generated from [`bom.csv`](bom.csv) by `tools/make_bom_md.py`. Edit the CSV, not this file.

This is the NEMA 8 build (the current Motor-Mirror Assembly). Prices are Sept 2026 estimates
in USD, not quotes; blank means already owned or not priced.

Status: **Have** = on the bench, **Print** = 3D printed, **To buy**, **Check** = confirm
whether it is already on hand, **TBD** = part not chosen yet.

## Electronics

| ID | Item | Spec | Qty | Est. unit ($) | Source | Status | Phase | Notes |
| --- | --- | --- | --- | --- | --- | --- | --- | --- |
| E1 | MCU | Adafruit ESP32 Feather V2 (product 5400) | 1 |  | Adafruit | Have | 1 | Runs the Arduino IDE sketch in firmware/optics_bench |
| E2 | Stepper driver | Adafruit TMC2209 breakout (product 6121) | 4 |  | Adafruit | Have | 1 | R_SENSE is 0.05 ohm. One shared UART bus; strap MS1/MS2 for addresses 0-3 |
| E3 | UART bus resistor | 1 kOhm 1/4 W | 1 |  | Stock | Have | 1 | Feather TX to the driver UART bus |
| E4 | Driver bulk capacitor | 100 uF 25 V electrolytic | 4 |  | Stock | Check | 1 | One across VM/GND at each driver |
| E5 | Control board PCB | electronics/pcb/control_board, 100 x 100 mm 2-layer (5 pcs) | 1 | 5 | JLCPCB / PCBWay | To buy | 1 | Upload fab/control_board/control_board_gerbers.zip as-is. Parts list: fab/control_board/control_board_bom.csv |
| E17 | Control board parts | 12 V input (PTC fuse, 1N5822, P6KE18CA, 470 uF), JST-XH plugs, sockets for the Feather, drivers and ADS1115 | 1 | 15 | DigiKey / LCSC | To buy | 1 | All through-hole; see control_board_bom.csv. Replaces the perfboard carrier |
| E18 | Photodiode board PCB | electronics/pcb/pd_amp, 34 x 25 mm 2-layer (5 pcs) | 1 | 2 | JLCPCB / PCBWay | To buy | 2 | Build two; replaces the photodiode perfboards (E15). Adds a 100 Ohm output resistor per board |
| E6 | Motor supply | 12 V 2 A DC | 1 | 8 | Amazon | Check | 1 | Skip if using a bench supply. Drivers only answer UART with 12 V on |
| E7 | Laser | Quarton VLM-635-32 LPT 635 nm module (Amazon B07QCTMMVT) | 1 |  | Amazon | Have | 1 | TTL high = on from GPIO 21. Measured beam about 7 x 3 mm |
| E8 | ADC | Adafruit ADS1115 16-bit I2C breakout (product 1085) | 1 | 15 | Adafruit | Check | 2 | Address 0x48 (ADDR to GND). Plugs into control board socket A2 (or the Feather STEMMA QT port when hand-wired). Adafruit ADS1X15 library |
| E9 | Photodiode | BPW34 Si PIN (5-pack) | 1 | 7 | Amazon / DigiKey | Check | 2 | One on each photodiode board: reference (ADS1115 A0) and fiber output (A1) |
| E10 | TIA op-amp | MCP6002 dual op-amp, DIP-8 | 2 | 0.5 | DigiKey | Check | 2 | One per photodiode board; half B unused, wired as a grounded follower |
| E11 | Hookup | Wire, headers, Dupont/JST connectors | 1 |  | Stock | Have | 1 |  |
| E12 | TIA feedback resistor | 47 kOhm 1% | 2 |  | Stock / DigiKey | Check | 2 | Rf on each board. Keep a few 10 kOhm on hand in case a channel saturates near 3.3 V (then update PD_*_TIA_OHMS in config.h) |
| E13 | TIA feedback capacitor | 1 nF C0G | 2 |  | Stock / DigiKey | Check | 2 | Cf across Rf; 47 us, about 3.4 kHz bandwidth |
| E14 | Op-amp decoupling capacitor | 100 nF ceramic | 2 |  | Stock / DigiKey | Check | 2 | Between MCP6002 pins 8 and 4, at the chip |
| E15 | Photodiode board | Small perfboard + short twisted pair to the ADS1115 | 2 |  | Stock / DigiKey | Check | 2 | Mounted right behind each diode; leads under 10 mm |
| E16 | STEMMA QT cable | JST SH 4-pin, 100 mm | 1 | 1 | Adafruit | Check | 2 | ADS1115 to the Feather STEMMA QT port |

## Motion

| ID | Item | Spec | Qty | Est. unit ($) | Source | Status | Phase | Notes |
| --- | --- | --- | --- | --- | --- | --- | --- | --- |
| M1 | Stepper motor | NEMA 8, 20 mm frame, 4 mm shaft, 0.6 A, 4-lead (StepperOnline 8HS15-0604S class) | 4 | 22 | Amazon | Have | 1 | Assembly model uses a 30 mm body. Longer body = more torque margin |
| M2 | Shaft adapter | Brass 3-to-4 mm adapter, 2x M3 set screws | 4 |  | Amazon | Have | 1 | Align one set screw with the motor D-flat |
| M3 | Drive rod | 3 mm round rod, 35 mm long, 2 mm hex tip | 4 |  | Hex key / rod stock | Have | 1 | Test-fit the tip in the adjuster socket (2.00 mm vs 5/64 in) |
| M4 | Rod bearing | 3x7x3 mm (683ZZ) | 4 |  | Amazon | Have | 1 | One per rod in the printed Motor Mount |
| M5 | Kinematic mirror mount | Compact 1 in, two 100 TPI hex adjusters (Thorlabs KMS style) | 2 |  | Thorlabs / eBay | Have | 1 | M1 and M2 in the Z-fold |
| M6 | Mirror | 1 in protected silver or aluminium | 2 |  | Thorlabs / eBay | Have | 1 |  |
| M7 | Motor screws | M2 x 4-5 mm | 8 |  | Amazon | Check | 1 | The M2x3 in the CAD model is too short; confirm what is fitted |
| M8 | Fastener kit | M3 screws + M3 heat-set inserts | 1 | 14 | Amazon | To buy | 1 | Brackets and base |
| M9 | Motor Mount | 3D printed (PETG) | 2 |  | Printer | Print | 1 | cad/assemblies Motor-Mirror Assembly |

## Optics

| ID | Item | Spec | Qty | Est. unit ($) | Source | Status | Phase | Notes |
| --- | --- | --- | --- | --- | --- | --- | --- | --- |
| O1 | Laser aperture | Printed plate, 2 mm hole | 1 |  | Printer | Print | 1 | 10-20 mm after the laser; trims the 7 x 3 mm beam |
| O2 | Polarizer film | Linear polarizer sheet (two pieces) | 1 | 8 | Amazon | To buy | 1 | Variable attenuator. Rotate only the first one |
| O3 | Beamsplitter | Plate or cube beamsplitter | 1 |  | TBD | TBD | 1 | Reflected port feeds the reference PD |
| O4 | Iris plates | Printed, 1.5 mm (also 1, 2, 3 mm) | 2 |  | Printer | Print | 1 | Print undersize and ream |
| O5 | Beam camera | Arducam OV9281 global-shutter UVC (B0332 class) | 1 | 40 | Amazon | Check | 1 | Remove the M12 lens; bare sensor as beam profiler |
| O6 | PD diffuser | Ground glass or frosted tape | 1 |  | Stock | To buy | 2 | 5-10 mm in front of the reference PD |

## Fiber

| ID | Item | Spec | Qty | Est. unit ($) | Source | Status | Phase | Notes |
| --- | --- | --- | --- | --- | --- | --- | --- | --- |
| F1 | Practice fiber | SMF-28 patch cable, FC/UPC, 1-3 m | 1 | 8 | Amazon / FS.com | To buy | 2 |  |
| F2 | Multimode fiber | 50/125 um patch cable, FC-FC, 1 m | 1 | 8 | Amazon / FS.com | To buy | 2 | First-light target |
| F3 | Single-mode fiber for red | Thorlabs P1-630A-FC-1 (630HP) | 1 | 90 | Thorlabs | To buy | 2 | Price not verified |
| F4 | FC bulkhead adapters | FC/FC square flange (5-pack) | 1 | 8 | Amazon | To buy | 2 | Fixed reference at the fiber and the output PD |
| F5 | Coupling lens | Glass asphere, f 8-11 mm, M9x0.5 cell | 2 | 6 | Amazon / AliExpress | To buy | 2 |  |
| F6 | Focus stage | 40 x 40 mm micrometer linear stage, 10+ mm travel | 1 | 30 | Amazon | To buy | 2 | Moves the lens |
| F7 | Fiber cleaner | One-click FC cleaner | 1 | 10 | Amazon | To buy | 2 | Nice to have |

## Base

| ID | Item | Spec | Qty | Est. unit ($) | Source | Status | Phase | Notes |
| --- | --- | --- | --- | --- | --- | --- | --- | --- |
| B1 | Bench base | Printed doweled sections, 25 mm insert grid | 1 |  | Printer | Print | 1 | About 420 x 260 mm; matte black near the beam |
| B2 | Dowel pins | Steel dowels for V-grooves | 1 | 8 | Amazon | To buy | 1 | About 50 um repeatability |

## Host

| ID | Item | Spec | Qty | Est. unit ($) | Source | Status | Phase | Notes |
| --- | --- | --- | --- | --- | --- | --- | --- | --- |
| H1 | Host computer | NVIDIA Jetson | 1 |  |  | Check | 1 | Camera + optimizer (ROS 2) |
| H2 | Bench instrument | Analog Discovery 3 | 1 |  |  | Check | 2 | Bench checks of the TIA and ADC |

**Estimated spend on To buy lines: $218** (excludes Check and TBD lines).

## Alternate: NEMA 11 build

Fall back to this if the knob torque test shows the adjusters need more than about 4 mN-m.
It swaps these lines; everything else stays the same.

| Replaces | With | Qty | Est. unit ($) |
| --- | --- | --- | --- |
| M1 NEMA 8 motor | NEMA 11, 28 mm frame, 45-51 mm body, 5 mm shaft, 10+ N-cm (StepperOnline 11HS20-0674S class) | 4 | 16 |
| M2 3-to-4 mm adapter | 5 mm to 5 mm shaft coupler | 4 | 3 |
| M3 3 mm drive rod | 5 mm steel rod, 100-200 mm, with bonded hex tip | 2 | 4 |
| M7 M2 motor screws | M3 screws (NEMA 11 flange) | 8 | |
| E6 12 V 2 A supply | 12 V 3 A supply | 1 | 10 |

The Motor Mount must be redrawn for the larger frame.

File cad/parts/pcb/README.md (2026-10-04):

# PCB models

STEP exports of the boards in `electronics/pcb`, for importing into Onshape:

| File | Board |
| --- | --- |
| `control_board.step` | Control board rev B, 100 x 100 x 1.6 mm, with the parts and the female sockets fitted |
| `pd_amp.step` | Photodiode amp board, 34.3 x 25.4 x 1.6 mm, with its parts fitted |

`control_board_3d.png` and `pd_amp_3d.png` are 3D renders of each board, for a quick look without a CAD tool.

These parts have no 3D model:
- The Feather, the TMC2209 breakouts and the ADS1115. Only their sockets are modelled. Adafruit publishes models for the boards themselves.
- F1, the PTC fuse on the control board.
- D1, the BPW34 on the photodiode board.

To regenerate after a board change, run this once for each board:

```
kicad-cli pcb export step -f --subst-models --include-silkscreen -o cad/parts/pcb/control_board.step electronics/pcb/control_board/control_board.kicad_pcb
```

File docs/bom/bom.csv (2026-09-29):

id | section | item | spec | qty | unit_usd | source | status | phase | notes
E1 | Electronics | MCU | Adafruit ESP32 Feather V2 (product 5400) | 1 |  | Adafruit | Have | 1 | Runs the Arduino IDE sketch in firmware/optics_bench
E2 | Electronics | Stepper driver | Adafruit TMC2209 breakout (product 6121) | 4 |  | Adafruit | Have | 1 | R_SENSE is 0.05 ohm. One shared UART bus; strap MS1/MS2 for addresses 0-3
E3 | Electronics | UART bus resistor | 1 kOhm 1/4 W | 1 |  | Stock | Have | 1 | Feather TX to the driver UART bus
E4 | Electronics | Driver bulk capacitor | 100 uF 25 V electrolytic | 4 |  | Stock | Check | 1 | One across VM/GND at each driver
E5 | Electronics | Control board PCB | electronics/pcb/control_board, 100 x 100 mm 2-layer (5 pcs) | 1 | 5 | JLCPCB / PCBWay | To buy | 1 | Upload fab/control_board/control_board_gerbers.zip as-is. Parts list: fab/control_board/control_board_bom.csv
E17 | Electronics | Control board parts | 12 V input (PTC fuse, 1N5822, P6KE18CA, 470 uF), JST-XH plugs, sockets for the Feather, drivers and ADS1115 | 1 | 15 | DigiKey / LCSC | To buy | 1 | All through-hole; see control_board_bom.csv. Replaces the perfboard carrier
E18 | Electronics | Photodiode board PCB | electronics/pcb/pd_amp, 34 x 25 mm 2-layer (5 pcs) | 1 | 2 | JLCPCB / PCBWay | To buy | 2 | Build two; replaces the photodiode perfboards (E15). Adds a 100 Ohm output resistor per board
E6 | Electronics | Motor supply | 12 V 2 A DC | 1 | 8 | Amazon | Check | 1 | Skip if using a bench supply. Drivers only answer UART with 12 V on
E7 | Electronics | Laser | Quarton VLM-635-32 LPT 635 nm module (Amazon B07QCTMMVT) | 1 |  | Amazon | Have | 1 | TTL high = on from GPIO 21. Measured beam about 7 x 3 mm
E8 | Electronics | ADC | Adafruit ADS1115 16-bit I2C breakout (product 1085) | 1 | 15 | Adafruit | Check | 2 | Address 0x48 (ADDR to GND). Plugs into control board socket A2 (or the Feather STEMMA QT port when hand-wired). Adafruit ADS1X15 library
E9 | Electronics | Photodiode | BPW34 Si PIN (5-pack) | 1 | 7 | Amazon / DigiKey | Check | 2 | One on each photodiode board: reference (ADS1115 A0) and fiber output (A1)
E10 | Electronics | TIA op-amp | MCP6002 dual op-amp, DIP-8 | 2 | 0.5 | DigiKey | Check | 2 | One per photodiode board; half B unused, wired as a grounded follower
E11 | Electronics | Hookup | Wire, headers, Dupont/JST connectors | 1 |  | Stock | Have | 1
E12 | Electronics | TIA feedback resistor | 47 kOhm 1% | 2 |  | Stock / DigiKey | Check | 2 | Rf on each board. Keep a few 10 kOhm on hand in case a channel saturates near 3.3 V (then update PD_*_TIA_OHMS in config.h)
E13 | Electronics | TIA feedback capacitor | 1 nF C0G | 2 |  | Stock / DigiKey | Check | 2 | Cf across Rf; 47 us, about 3.4 kHz bandwidth
E14 | Electronics | Op-amp decoupling capacitor | 100 nF ceramic | 2 |  | Stock / DigiKey | Check | 2 | Between MCP6002 pins 8 and 4, at the chip
E15 | Electronics | Photodiode board | Small perfboard + short twisted pair to the ADS1115 | 2 |  | Stock / DigiKey | Check | 2 | Mounted right behind each diode; leads under 10 mm
E16 | Electronics | STEMMA QT cable | JST SH 4-pin, 100 mm | 1 | 1 | Adafruit | Check | 2 | ADS1115 to the Feather STEMMA QT port
M1 | Motion | Stepper motor | NEMA 8, 20 mm frame, 4 mm shaft, 0.6 A, 4-lead (StepperOnline 8HS15-0604S class) | 4 | 22 | Amazon | Have | 1 | Assembly model uses a 30 mm body. Longer body = more torque margin
M2 | Motion | Shaft adapter | Brass 3-to-4 mm adapter, 2x M3 set screws | 4 |  | Amazon | Have | 1 | Align one set screw with the motor D-flat
M3 | Motion | Drive rod | 3 mm round rod, 35 mm long, 2 mm hex tip | 4 |  | Hex key / rod stock | Have | 1 | Test-fit the tip in the adjuster socket (2.00 mm vs 5/64 in)
M4 | Motion | Rod bearing | 3x7x3 mm (683ZZ) | 4 |  | Amazon | Have | 1 | One per rod in the printed Motor Mount
M5 | Motion | Kinematic mirror mount | Compact 1 in, two 100 TPI hex adjusters (Thorlabs KMS style) | 2 |  | Thorlabs / eBay | Have | 1 | M1 and M2 in the Z-fold
M6 | Motion | Mirror | 1 in protected silver or aluminium | 2 |  | Thorlabs / eBay | Have | 1
M7 | Motion | Motor screws | M2 x 4-5 mm | 8 |  | Amazon | Check | 1 | The M2x3 in the CAD model is too short; confirm what is fitted
M8 | Motion | Fastener kit | M3 screws + M3 heat-set inserts | 1 | 14 | Amazon | To buy | 1 | Brackets and base
M9 | Motion | Motor Mount | 3D printed (PETG) | 2 | 0 | Printer | Print | 1 | cad/assemblies Motor-Mirror Assembly
O1 | Optics | Laser aperture | Printed plate, 2 mm hole | 1 | 0 | Printer | Print | 1 | 10-20 mm after the laser; trims the 7 x 3 mm beam
O2 | Optics | Polarizer film | Linear polarizer sheet (two pieces) | 1 | 8 | Amazon | To buy | 1 | Variable attenuator. Rotate only the first one
O3 | Optics | Beamsplitter | Plate or cube beamsplitter | 1 |  | TBD | TBD | 1 | Reflected port feeds the reference PD
O4 | Optics | Iris plates | Printed, 1.5 mm (also 1, 2, 3 mm) | 2 | 0 | Printer | Print | 1 | Print undersize and ream
O5 | Optics | Beam camera | Arducam OV9281 global-shutter UVC (B0332 class) | 1 | 40 | Amazon | Check | 1 | Remove the M12 lens; bare sensor as beam profiler
O6 | Optics | PD diffuser | Ground glass or frosted tape | 1 |  | Stock | To buy | 2 | 5-10 mm in front of the reference PD
F1 | Fiber | Practice fiber | SMF-28 patch cable, FC/UPC, 1-3 m | 1 | 8 | Amazon / FS.com | To buy | 2
F2 | Fiber | Multimode fiber | 50/125 um patch cable, FC-FC, 1 m | 1 | 8 | Amazon / FS.com | To buy | 2 | First-light target
F3 | Fiber | Single-mode fiber for red | Thorlabs P1-630A-FC-1 (630HP) | 1 | 90 | Thorlabs | To buy | 2 | Price not verified
F4 | Fiber | FC bulkhead adapters | FC/FC square flange (5-pack) | 1 | 8 | Amazon | To buy | 2 | Fixed reference at the fiber and the output PD
F5 | Fiber | Coupling lens | Glass asphere, f 8-11 mm, M9x0.5 cell | 2 | 6 | Amazon / AliExpress | To buy | 2
F6 | Fiber | Focus stage | 40 x 40 mm micrometer linear stage, 10+ mm travel | 1 | 30 | Amazon | To buy | 2 | Moves the lens
F7 | Fiber | Fiber cleaner | One-click FC cleaner | 1 | 10 | Amazon | To buy | 2 | Nice to have
B1 | Base | Bench base | Printed doweled sections, 25 mm insert grid | 1 | 0 | Printer | Print | 1 | About 420 x 260 mm; matte black near the beam
B2 | Base | Dowel pins | Steel dowels for V-grooves | 1 | 8 | Amazon | To buy | 1 | About 50 um repeatability
H1 | Host | Host computer | NVIDIA Jetson | 1 |  |  | Check | 1 | Camera + optimizer (ROS 2)
H2 | Host | Bench instrument | Analog Discovery 3 | 1 |  |  | Check | 2 | Bench checks of the TIA and ADC

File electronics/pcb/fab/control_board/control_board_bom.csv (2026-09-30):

refs | qty | description | part number | footprint
A1 | 1 | Adafruit ESP32 Feather V2 (on hand) | Adafruit 5400
A2 | 1 | Adafruit ADS1115 breakout | Adafruit 1085
C1 C2 C3 C4 | 4 | 100 uF 25 V electrolytic, 6.3 mm, 2.5 mm pitch | Panasonic EEU-FR1E101 | Capacitor_THT:CP_Radial_D6.3mm_P2.50mm
C5 | 1 | 470 uF 25 V electrolytic, 10 mm, 5 mm pitch | Panasonic EEU-FR1E471 | Capacitor_THT:CP_Radial_D10.0mm_P5.00mm
D1 | 1 | Schottky diode 3 A 40 V, DO-201AD | 1N5822 | Diode_THT:D_DO-201AD_P15.24mm_Horizontal
D2 | 1 | TVS 600 W, 15.3 V standoff, bidirectional, DO-15 | Littelfuse P6KE18CA | Diode_THT:D_DO-15_P10.16mm_Horizontal
D3 | 1 | 3 mm green LED | generic | LED_THT:LED_D3.0mm
F1 | 1 | PTC resettable fuse, 2 A hold | Bourns MF-RHT200 | Fuse:Fuse_Bourns_MF-RHT200
J1 J2 J3 J4 | 4 | JST-XH 2-pin header, vertical (driver VM feed) | JST B2B-XH-A(LF)(SN) | Connector_JST:JST_XH_B2B-XH-A_1x02_P2.50mm_Vertical
J5 | 1 | Screw terminal 2-pin 5.08 mm (MKDS 1,5/2-5,08) | Phoenix Contact 1729128 | TerminalBlock_Phoenix:TerminalBlock_Phoenix_MKDS-1,5-2-5.08_1x02_P5.08mm_Horizontal
J6 | 1 | DC barrel jack 5.5 x 2.1 mm | CUI PJ-102AH | Connector_BarrelJack:BarrelJack_Horizontal
J7 J8 J9 | 3 | JST-XH 3-pin header, vertical | JST B3B-XH-A(LF)(SN) | Connector_JST:JST_XH_B3B-XH-A_1x03_P2.50mm_Vertical
J10 | 1 | 1x10 male pin header 2.54 mm | generic | Connector_PinHeader_2.54mm:PinHeader_1x10_P2.54mm_Vertical
R1 | 1 | 1 kOhm 1/4 W axial | generic | Resistor_THT:R_Axial_DIN0207_L6.3mm_D2.5mm_P10.16mm_Horizontal
R2 | 1 | 4.7 kOhm 1/4 W axial | generic | Resistor_THT:R_Axial_DIN0207_L6.3mm_D2.5mm_P10.16mm_Horizontal
U1 U2 U3 U4 | 4 | Adafruit TMC2209 breakout (on hand) | Adafruit 6121
A1 socket | 1 | Female header 1x16, 2.54 mm, 8.5 mm tall | generic (e.g. Adafruit 2940 kit)
A1 socket | 1 | Female header 1x12, 2.54 mm, 8.5 mm tall | generic (e.g. Adafruit 2940 kit)
U1-U4 sockets | 4 | Female header 1x10, 2.54 mm | generic
U1-U4 standoffs | 8 | M2 x 11 mm standoff + 2 M2 screws, under each breakout's terminal-end holes | generic
J1-J4 VM leads | 4 | JST-XH 2-pin lead, about 60 mm, bare ends into the breakout's VM + / - terminals | JST
A2 socket | 1 | Female header 1x10, 2.54 mm | generic
J7-J9 cables | 1 | JST-XH housings (XHP-3) and SXH-001T-P0.6 crimps, or pre-crimped leads | JST

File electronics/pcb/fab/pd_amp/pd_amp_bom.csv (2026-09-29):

refs | qty | description | part number | footprint
C1 | 1 | 1 nF C0G/NP0 50 V, 5 mm pitch (Cf) | generic | Capacitor_THT:C_Disc_D5.0mm_W2.5mm_P5.00mm
C2 | 1 | 100 nF X7R 50 V, 5 mm pitch | generic | Capacitor_THT:C_Disc_D5.0mm_W2.5mm_P5.00mm
D1 | 1 | Silicon PIN photodiode | Vishay BPW34 | OptoDevice:Osram_DIL2_4.3x4.65mm_P5.08mm
J1 | 1 | JST-XH 3-pin header, vertical | JST B3B-XH-A(LF)(SN) | Connector_JST:JST_XH_B3B-XH-A_1x03_P2.50mm_Vertical
R1 | 1 | 47 kOhm 1% 1/4 W axial (Rf) | generic | Resistor_THT:R_Axial_DIN0207_L6.3mm_D2.5mm_P7.62mm_Horizontal
R2 | 1 | 100 Ohm 1/4 W axial | generic | Resistor_THT:R_Axial_DIN0207_L6.3mm_D2.5mm_P7.62mm_Horizontal
U1 | 1 | Dual op-amp, DIP-8 | Microchip MCP6002-I/P | Package_DIP:DIP-8_W7.62mm
U1 | 1 | DIP-8 socket (optional) | generic
J1 cable | 1 | JST-XH 3-pin lead, wired 1:1 to control board J8 or J9 | JST

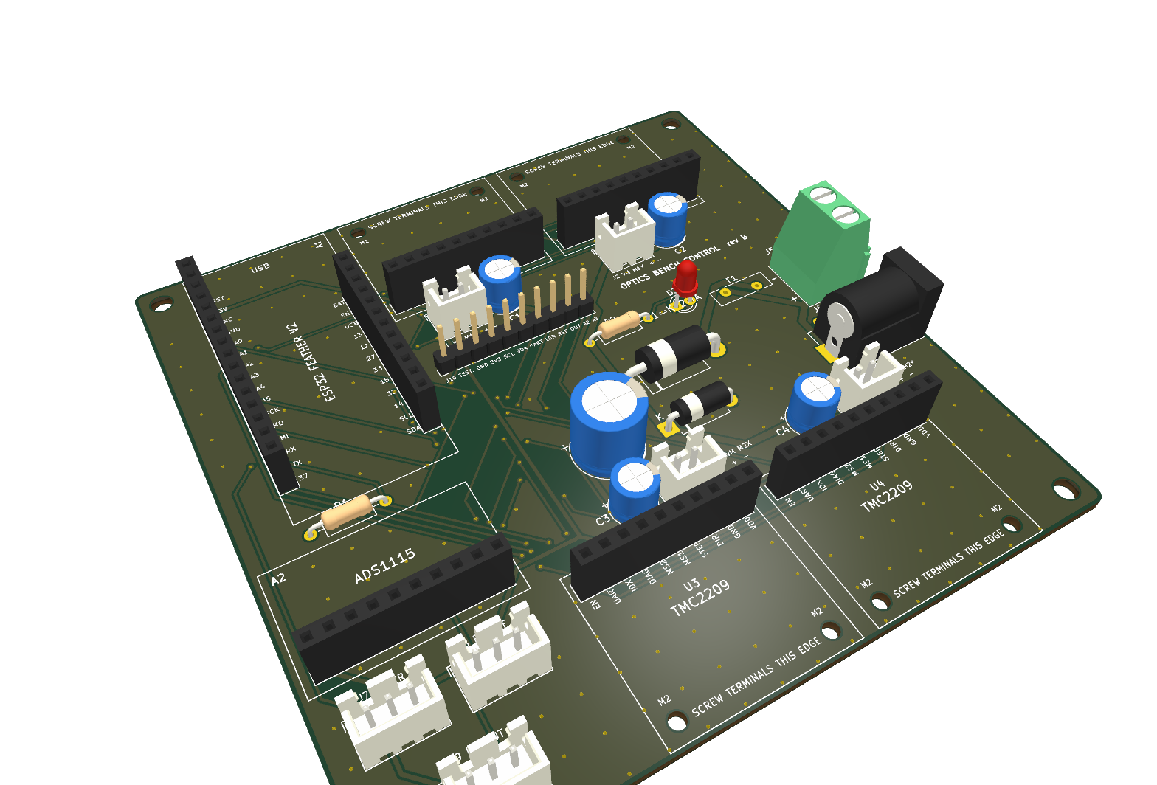
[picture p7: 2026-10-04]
cad/parts/pcb/control_board_3d.png

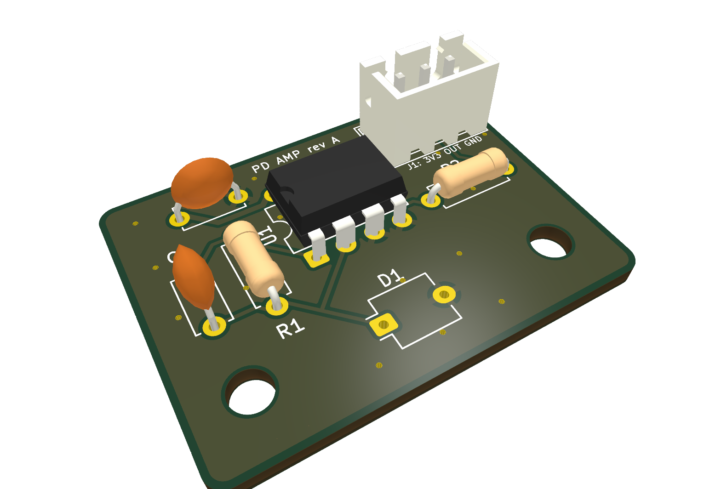
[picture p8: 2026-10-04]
cad/parts/pcb/pd_amp_3d.png

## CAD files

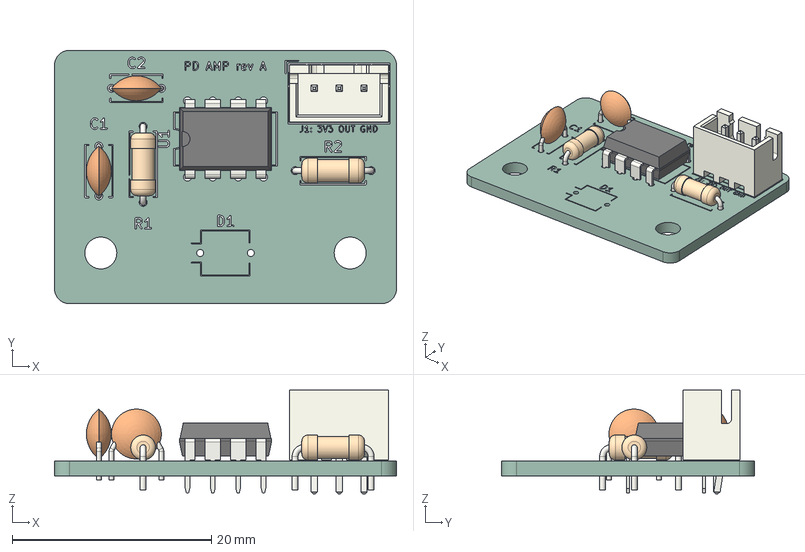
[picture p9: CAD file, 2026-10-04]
cad/parts/pcb/pd_amp.step
34.3 x 25.4 x 10.4 mm
JST_B3B_XH_A
R_Axial_DIN0207_L63mm_D25mm_P762mm_Horizontal x 2
C_Disc_D50mm_W25mm_P500mm x 2
DIP-8_W7.62mm
pd_amp_silkscreen
pd_amp_PCB

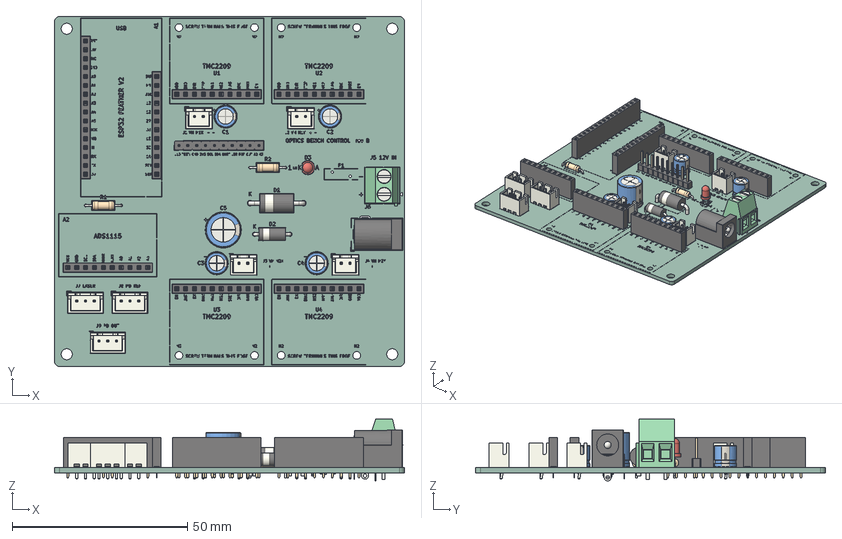
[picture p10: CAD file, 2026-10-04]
cad/parts/pcb/control_board.step
100.0 x 100.0 x 17.7 mm
TerminalBlock_Phoenix_MKDS-1,5-2-5.08_1x02_P5.08mm_Horizontal
JST_B2B_XH_A x 4
D_DO-15_P10.16mm_Horizontal
PinSocket_1x10_P2.54mm_Vertical x 5
R_Axial_DIN0207_L63mm_D25mm_P1016mm_Horizontal x 2
CP_Radial_D63mm_P250mm x 4
PinSocket_1x16_P2.54mm_Vertical
PinSocket_1x12_P2.54mm_Vertical
JST_B3B_XH_A x 3
PinHeader_1x10_P254mm_Vertical
BarrelJack_Horizontal
CP_Radial_D100mm_P500mm
LED_D3.0mm
D_DO-201AD_P15.24mm_Horizontal
control_board_silkscreen
control_board_PCB

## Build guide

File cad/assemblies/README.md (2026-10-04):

# Assemblies

| File | What it is |
| --- | --- |
| `ros_laser_bench_main_assembly.step` | The whole bench as built in Onshape: breadboard, optics, both motor-mirror assemblies and the electronics, in place (STEP AP242, about 28 MB) |

Bench overview

The file keeps Onshape's assembly tree, so it opens in any CAD tool with every subassembly and part separate and named. Part Studios have no equivalent in STEP, so each part sits under the subassembly it was inserted into. Only parts placed in the assembly are included.

## What's in the main assembly

Listed in beam order, with the Onshape name of each subassembly.

| Subassembly | Count | Role on the bench |
| --- | --- | --- |
| `Laser Assembly` | 1 | 635 nm laser module in its tube, lens holder and mount |
| `2 mm aperture` | 1 | Printed aperture just after the laser, trims the 7 x 3 mm beam |
| `Linear Polarizer Assembly` | 1 | Polarizer film in a holder on a Y mount (attenuator) |
| `Assembly 1` | 1 | Beamsplitter with its mount, clamp and backing; sends a slice of the beam to the reference photodiode |
| `Photodiode Mount Assembly` | 2 | Photodiode on an 18 mm post: one on the beamsplitter's reflected port (reference), one behind the output fiber |
| `Motor-Mirror Assembly` | 2 | M1 and M2: a kinematic mount with a silver mirror, tip and tilt turned by two NEMA 8 motors through 2 mm hex rods |
| `1 mm aperture` | 2 | The two printed irises that define the beam axis |
| `Lens Mount Assembly` | 1 | Asphere in its holder on an 18 mm post (focusing lens; the OV9281 camera takes its place in phase 1) |
| `Fiber Mount Assembly` | 2 | FC bulkhead on a 17 mm post: the input fiber at the lens focus, and the fiber output at the output photodiode |
| `Electronics Assembly` | 1 | Control board with the Feather, four TMC2209 breakouts and the ADS1115, plus one photodiode amp board |
| `Optical Breadboard` | 1 | The printed base: four tiles on the 25 mm hole grid, with the parts that join them |

Each `Motor-Mirror Assembly` contains the motor mount, two NEMA 8 motors, two 3-to-4 mm brass adapters with M3 set screws, two 3x7x3 bearings, two hex rods, eight M2x3 screws, the kinematic mirror mount and the mirror.

Notes on the model:
- The Feather in `Electronics Assembly` is Adafruit's ESP8266 Feather model (2821), standing in for the ESP32 Feather V2 the firmware targets. The two boards share the Feather outline and header positions.
- The control board and photodiode amp models are the KiCad exports in [`cad/parts/pcb`](../parts/pcb/README.md).
- The photodiodes are placeholders (`Dummy PhotoDiode`).

To update, export the main assembly from Onshape as STEP with **Flatten assembly** unticked, replace the file here, and say what changed in the commit message.

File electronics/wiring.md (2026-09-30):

# Wiring: ESP32, motor drivers, laser and photodiodes

The electronics can be built two ways:

- **Control board (recommended).** A 2-layer carrier PCB takes the Feather, the four TMC2209 breakouts and the ADS1115 on sockets, and makes every connection below in copper. Cables go to the motors, laser, photodiode boards and 12 V supply. For the board, ordering and assembly, see [pcb/README.md](pcb/README.md). For every cable on the bench, see the system diagram below.
- **Hand wiring** on perfboard, using the pin tables below. The nets are the same.

System wiring

Pin-level wiring (the same connections the control board makes):

Wiring diagram

Parts:

- [Adafruit ESP32 Feather V2](https://www.adafruit.com/product/5400) (product 5400)
- 4x [Adafruit TMC2209 stepper driver breakout](https://www.adafruit.com/product/6121) (product 6121)
- Quarton VLM-635-32 LPT laser module (635 nm, TTL modulation)
- [Adafruit ADS1115 16-bit ADC breakout](https://www.adafruit.com/product/1085) (product 1085) and a STEMMA QT cable
- 2x photodiode boards, each with a BPW34 photodiode, an MCP6002 op-amp (DIP-8), a 47 kOhm 1% resistor, a 1 nF C0G capacitor and a 100 nF decoupling capacitor

The pins match `firmware/optics_bench/config.h`. If you change a pin there, change it here too, and regenerate the diagram with `python electronics/make_wiring_svg.py electronics/wiring.svg`.

## Feather ESP32 V2 pins

| Feather pad | GPIO | Goes to |
| --- | --- | --- |
| 3V3 | | VDD on all four drivers, MS1/MS2 straps that are tied high, laser +V, ADS1115 VDD, both photodiode boards |
| GND | | GND on all four drivers, laser GND, 12 V supply minus, ADS1115 GND and ADDR, both photodiode boards |
| RX | 7 | UART bus (direct) |
| TX | 8 | UART bus through a 1 kOhm resistor |
| A5 | 4 | M1X STEP |
| 13 | 13 | M1X DIR (also the Feather's red LED, so it flickers) |
| 12 | 12 | M1X EN |
| 27 | 27 | M1Y STEP |
| 33 | 33 | M1Y DIR |
| 15 | 15 | M1Y EN |
| 32 | 32 | M2X STEP |
| 14 | 14 | M2X DIR |
| A1 | 25 | M2X EN |
| A0 | 26 | M2Y STEP |
| SCK | 5 | M2Y DIR |
| MO | 19 | M2Y EN |
| MI | 21 | Laser TTL |
| SDA | 22 | ADS1115 SDA |
| SCL | 20 | ADS1115 SCL |
| A2 | 34 (input only) | M1X DIAG (control board; optional when hand-wiring) |
| A3 | 39 (input only) | M1Y DIAG (control board) |
| A4 | 36 (input only) | M2X DIAG (control board) |
| 37 | 37 (input only) | M2Y DIAG (control board) |

## TMC2209 breakouts

Header pins in board order. Each driver's MS1/MS2 pins set its UART address.

| Pin | M1X (addr 0) | M1Y (addr 1) | M2X (addr 2) | M2Y (addr 3) |
| --- | --- | --- | --- | --- |
| 1 VDD | 3V3 | 3V3 | 3V3 | 3V3 |
| 2 GND | GND | GND | GND | GND |
| 3 DIR | GPIO 13 | GPIO 33 | GPIO 14 | GPIO 5 (SCK) |
| 4 STEP | GPIO 4 (A5) | GPIO 27 | GPIO 32 | GPIO 26 (A0) |
| 5 MS1 | GND | 3V3 | GND | 3V3 |
| 6 MS2 | GND | GND | 3V3 | 3V3 |
| 7 DIAG | A2 (I34) | A3 (I39) | A4 (I36) | 37 (I37) |
| 8 INDEX | not connected | not connected | not connected | not connected |
| 9 UART | UART bus | UART bus | UART bus | UART bus |
| 10 EN | GPIO 12 | GPIO 15 | GPIO 25 (A1) | GPIO 19 (MO) |

Screw terminals on each breakout:

| Terminal | Goes to |
| --- | --- |
| + (VMotor) | 12 V supply plus (control board: VM plug J1-J4 pin 1, next to the driver) |
| - (GND) | 12 V supply minus (control board: VM plug J1-J4 pin 2) |
| 1A / 1B | One motor coil |
| 2A / 2B | The other motor coil |

DIAG goes high on a driver fault or stall. The firmware doesn't read it yet, and on a hand-wired build it can stay unconnected.

On the control board each breakout keeps its screw terminals and plugs in by the 10-pin logic header only. The motors wire straight into the breakout's terminals. A 2-wire lead from the carrier's VM plug next to each driver (J1-J4: pin 1 = +12 V, pin 2 = GND) goes to the breakout's + and - terminals.

## Laser (Quarton VLM-635-32 LPT)

| Laser wire | Goes to |
| --- | --- |
| +V | Feather 3V3 (module runs on 3-6 V and draws under 40 mA) |
| GND | Feather GND |
| TTL | Feather MI (GPIO 21). High turns the laser on. The input takes 1-20 mA, which a GPIO can drive directly. |

Check which wire is which on the module's label. Red is usually +V and black is usually GND.

## Photodiodes and ADC

Two BPW34 photodiodes measure the light: the reference diode sits behind the beamsplitter's reflected port and the output diode sits behind the fiber. Each diode has its own transimpedance amplifier (TIA) on a small board right behind it, which turns the photocurrent into a voltage. The ADS1115 reads both voltages and sends them to the Feather over I2C.

### ADS1115 breakout

| ADS1115 pin | Goes to |
| --- | --- |
| VDD | Feather 3V3 |
| GND | Feather GND |
| SCL | Feather SCL (GPIO 20) |
| SDA | Feather SDA (GPIO 22) |
| ADDR | GND, which sets the I2C address to 0x48 |
| ALRT | not connected |
| A0 | Vout of the reference photodiode board |
| A1 | Vout of the output photodiode board |
| A2, A3 | not connected |

A STEMMA QT cable between the ADS1115 and the Feather's STEMMA QT port carries VDD, GND, SDA and SCL in one plug. The Feather V2 powers that port from GPIO 2, which the ESP32 board package switches on at boot. Then only ADDR, A0 and A1 need wires.

### Photodiode board (build two)

The [pd_amp PCB](pcb/README.md) is this circuit, plus a 100 Ohm resistor in series with the output that isolates the cable capacitance. Its J1 (1 = 3V3, 2 = VOUT, 3 = GND) plugs 1:1 into control board J8 (reference, A0) or J9 (output, A1). The table below covers a perfboard build.

| Part | Connection |
| --- | --- |
| BPW34 cathode | MCP6002 pin 2 (input A, minus) |
| BPW34 anode | GND |
| Rf 47 kOhm | Between pin 1 (output A) and pin 2 |
| Cf 1 nF C0G | Across Rf, also between pin 1 and pin 2 |
| MCP6002 pin 3 (input A, plus) | GND |
| MCP6002 pin 8 (VDD) | Feather 3V3 |
| MCP6002 pin 4 (VSS) | GND |
| 100 nF | Between pins 8 and 4, right at the chip |
| MCP6002 pin 5 | GND (half B is unused) |
| MCP6002 pin 6 | Pin 7 (half B as a grounded follower) |
| Pin 1 (Vout) | ADS1115 A0 (reference board) or A1 (output board) |

The diode works at zero bias, so the output sits at 0 V in the dark and rises as `Vout = I_photo x Rf`.

- **Finding the anode.** In room light, a multimeter on DC volts reads about +0.3 V across the diode with the red probe on the anode.
- **Why 47 kOhm.** The laser is under 1 mW. A BPW34 gives about 0.4 A/W at 635 nm, so 47 kOhm reaches the 3.3 V rail at 70 uA, about 175 uW on the diode. The ADS1115's gain ranges cover the dim end, down to about 0.4 nW per count. If a channel sits near 3.3 V, fit a smaller Rf on that board and change `PD_REF_TIA_OHMS` or `PD_OUT_TIA_OHMS` in `config.h`, because the test panel works out microwatts from those values.
- **Bandwidth.** Rf x Cf is 47 us, a 3.4 kHz bandwidth, which is much faster than the ADC samples and keeps the amplifier stable.
- **Leads.** Keep the diode leads under 10 mm, and run Vout and GND to the ADS1115 as a twisted pair.
- **Offset.** The MCP6002's input offset is a few millivolts. On a 3.3 V single supply a negative offset clips at 0 V, so the dark reading may be 0 V or a few millivolts. `PD DARK` in the firmware measures that offset with the laser off and subtracts it.

## Things to know

- **One ground.** The 12 V supply minus, the Feather GND, every breakout GND and both photodiode boards must all be connected together. Run the photodiode grounds back to the Feather rather than to the motor supply, so motor current doesn't flow through them.
- **UART bus.** The Adafruit breakout connects its UART pin straight to the chip with no resistor. Join all four UART pins into one bus. Connect the Feather RX to the bus directly and the Feather TX through a 1 kOhm resistor.
- **Addresses.** MS1 and MS2 have no pull resistors on the breakout. Tie every one of them to 3V3 or GND as shown above; don't leave them floating.
- **12 V comes first for UART.** The TMC2209 runs its logic from the motor supply, so a driver doesn't answer on UART until 12 V is on. The firmware retries when you move that axis, or you can send `REPROBE ALL`.
- **Sense resistors are 0.05 Ohm** on this breakout, not the 0.11 Ohm used on BTT/FYSETC modules. `config.h` has `R_SENSE 0.05f`. With the wrong value the motors would get almost double the current you set.
- **Current pot and SPREAD jumper.** The firmware sets the motor current and StealthChop over UART, so the pot does nothing. Leave the SPREAD solder jumper open.
- **EN at power-up.** The breakout pulls EN low (a 20 kOhm resistor), so the drivers are enabled until the firmware boots and drives EN high. That pull-down also keeps GPIO 12 low at reset, which the ESP32 needs to boot.
- **Motor coils.** To find a coil pair, measure resistance between the motor's wires. The two wires with a few ohms between them are one coil: put them on 1A/1B and the other pair on 2A/2B. If a motor turns the wrong way, set `invert` for that axis in `config.h` instead of rewiring.
- Never plug or unplug a motor while the 12 V supply is on.

## Host and bench instruments

| From | To | Cable |
| --- | --- | --- |
| Jetson USB-A | Feather USB-C | USB data cable. Serial at 115200 baud, and it powers the Feather's 3V3 rail |
| Jetson USB-A | Arducam OV9281 | USB (UVC camera, beam profiler for phase 1). No other wiring |
| 12 V 2 A supply | Control board J6 (5.5 x 2.1 mm, centre +) or J5 (screw terminal) | One or the other |
| Analog Discovery 3 | Control board J10 test header | Flywires: GND to pin 1, scope 1+ to pin 7 (PD_REF), scope 2+ to pin 8 (PD_OUT), DIO 0 to pin 5 (UART bus), DIO 1 to pin 6 (laser TTL), DIO 2/3 to pins 3/4 (SCL/SDA). Leave V+ and V- unconnected |

The Analog Discovery's ground is the laptop's USB ground. Its GND flywire ties it to the bench ground at J10, and the scope's minus inputs go to GND too.

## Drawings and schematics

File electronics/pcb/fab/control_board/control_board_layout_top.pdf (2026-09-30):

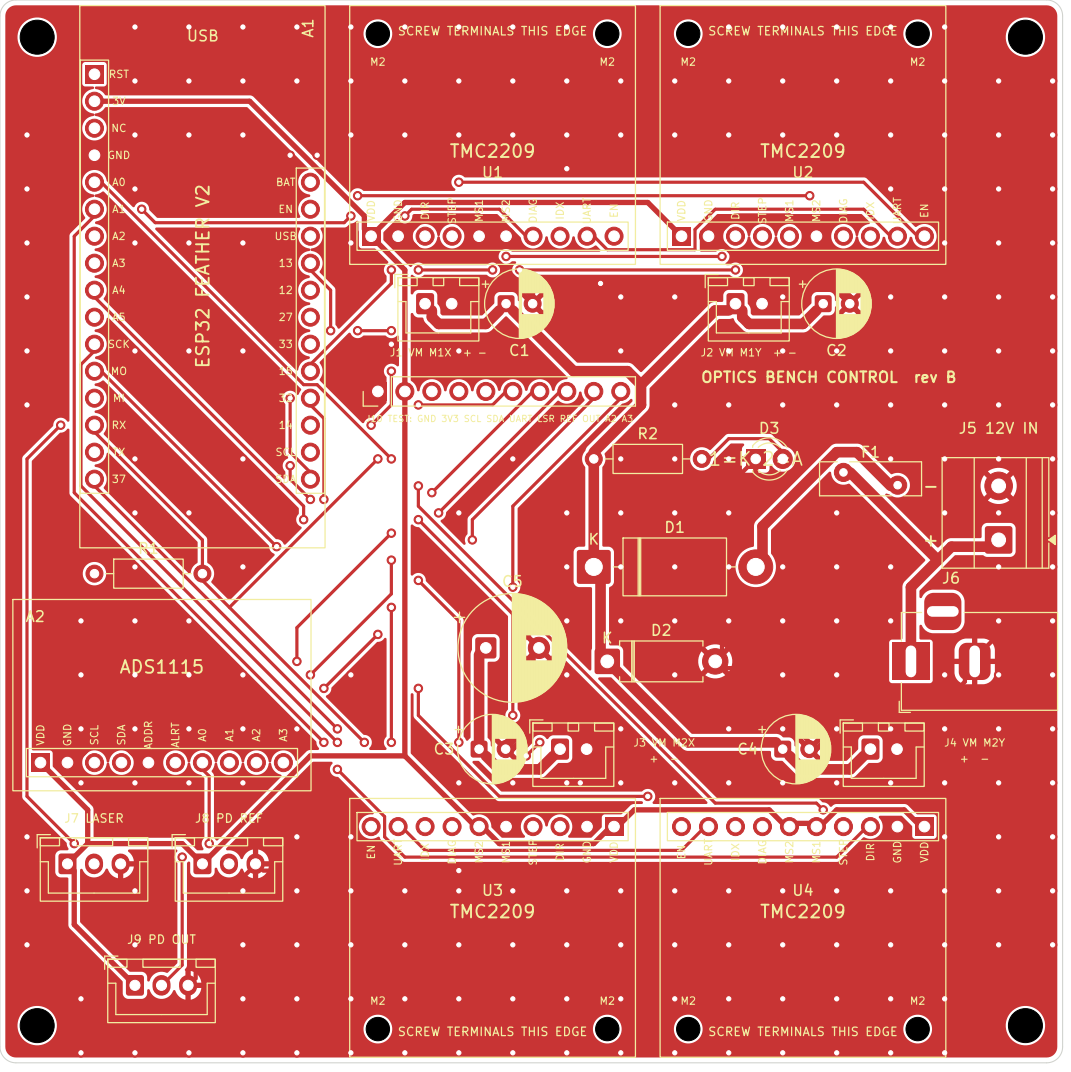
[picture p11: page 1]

OPTICS BENCH CONTROL rev B -

J10 TEST: GND 3V3 SCL SDA UART LSR REF OUT A2 A3

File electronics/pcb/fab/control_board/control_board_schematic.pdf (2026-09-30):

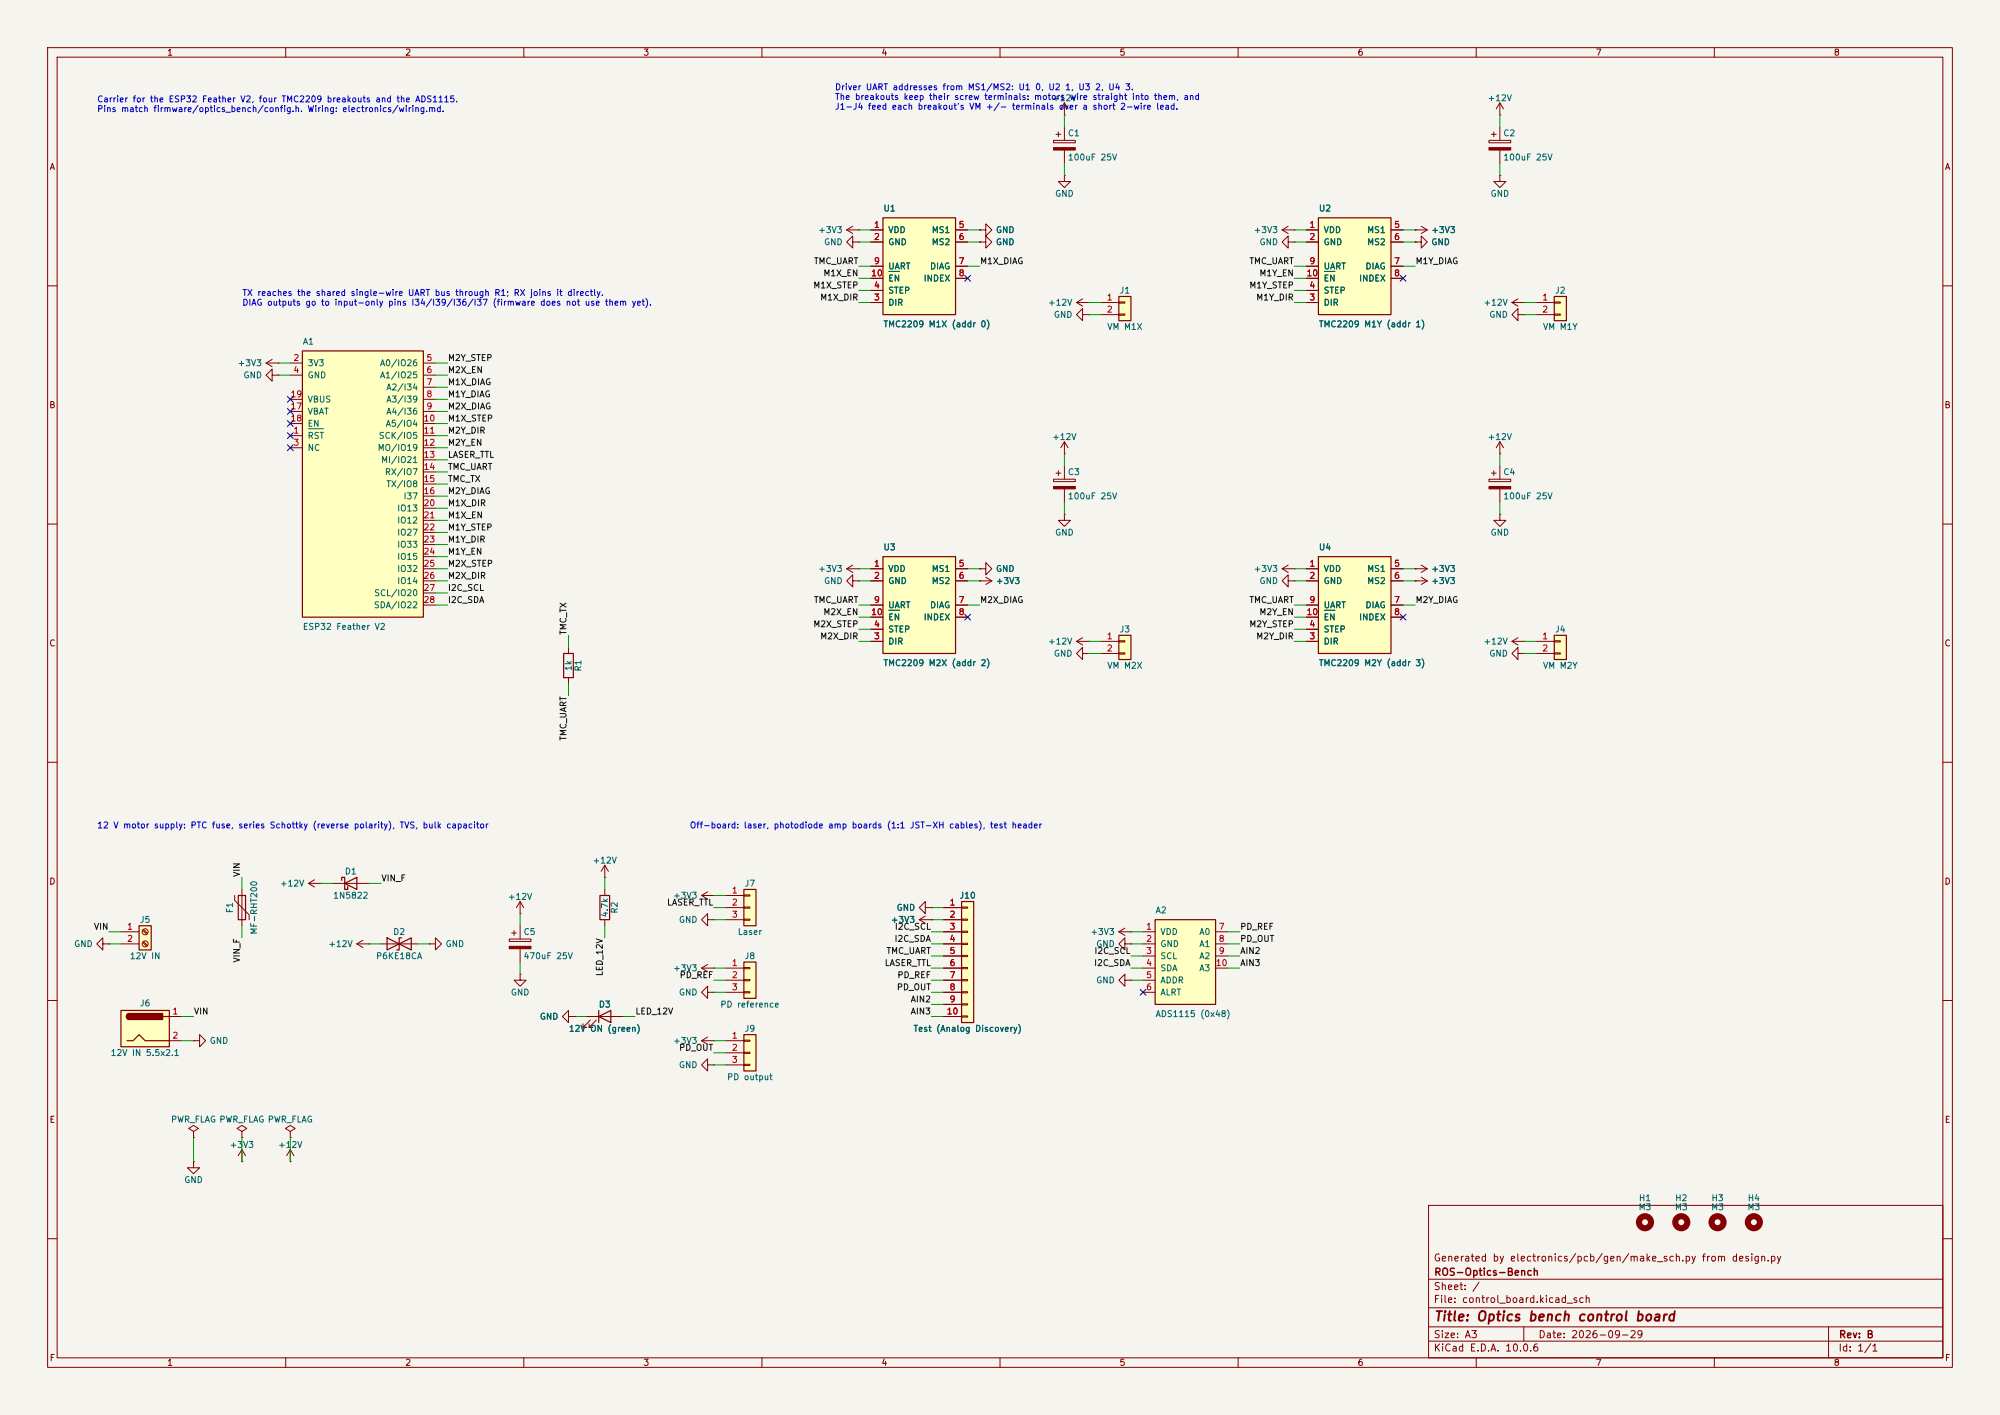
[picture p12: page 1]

J1-J4 feed each breakout's VM +/- terminals over a short 2-wire lead.

Generated by electronics/pcb/gen/make_sch.py from design.py
ROS-Optics-Bench
Sheet: /
File: control_board.kicad_sch
Title: Optics bench control board

Size: A3 | Rev: B | F Date: 2026-09-29
KiCad E.D.A. 10.0.6 | Id: 1/1

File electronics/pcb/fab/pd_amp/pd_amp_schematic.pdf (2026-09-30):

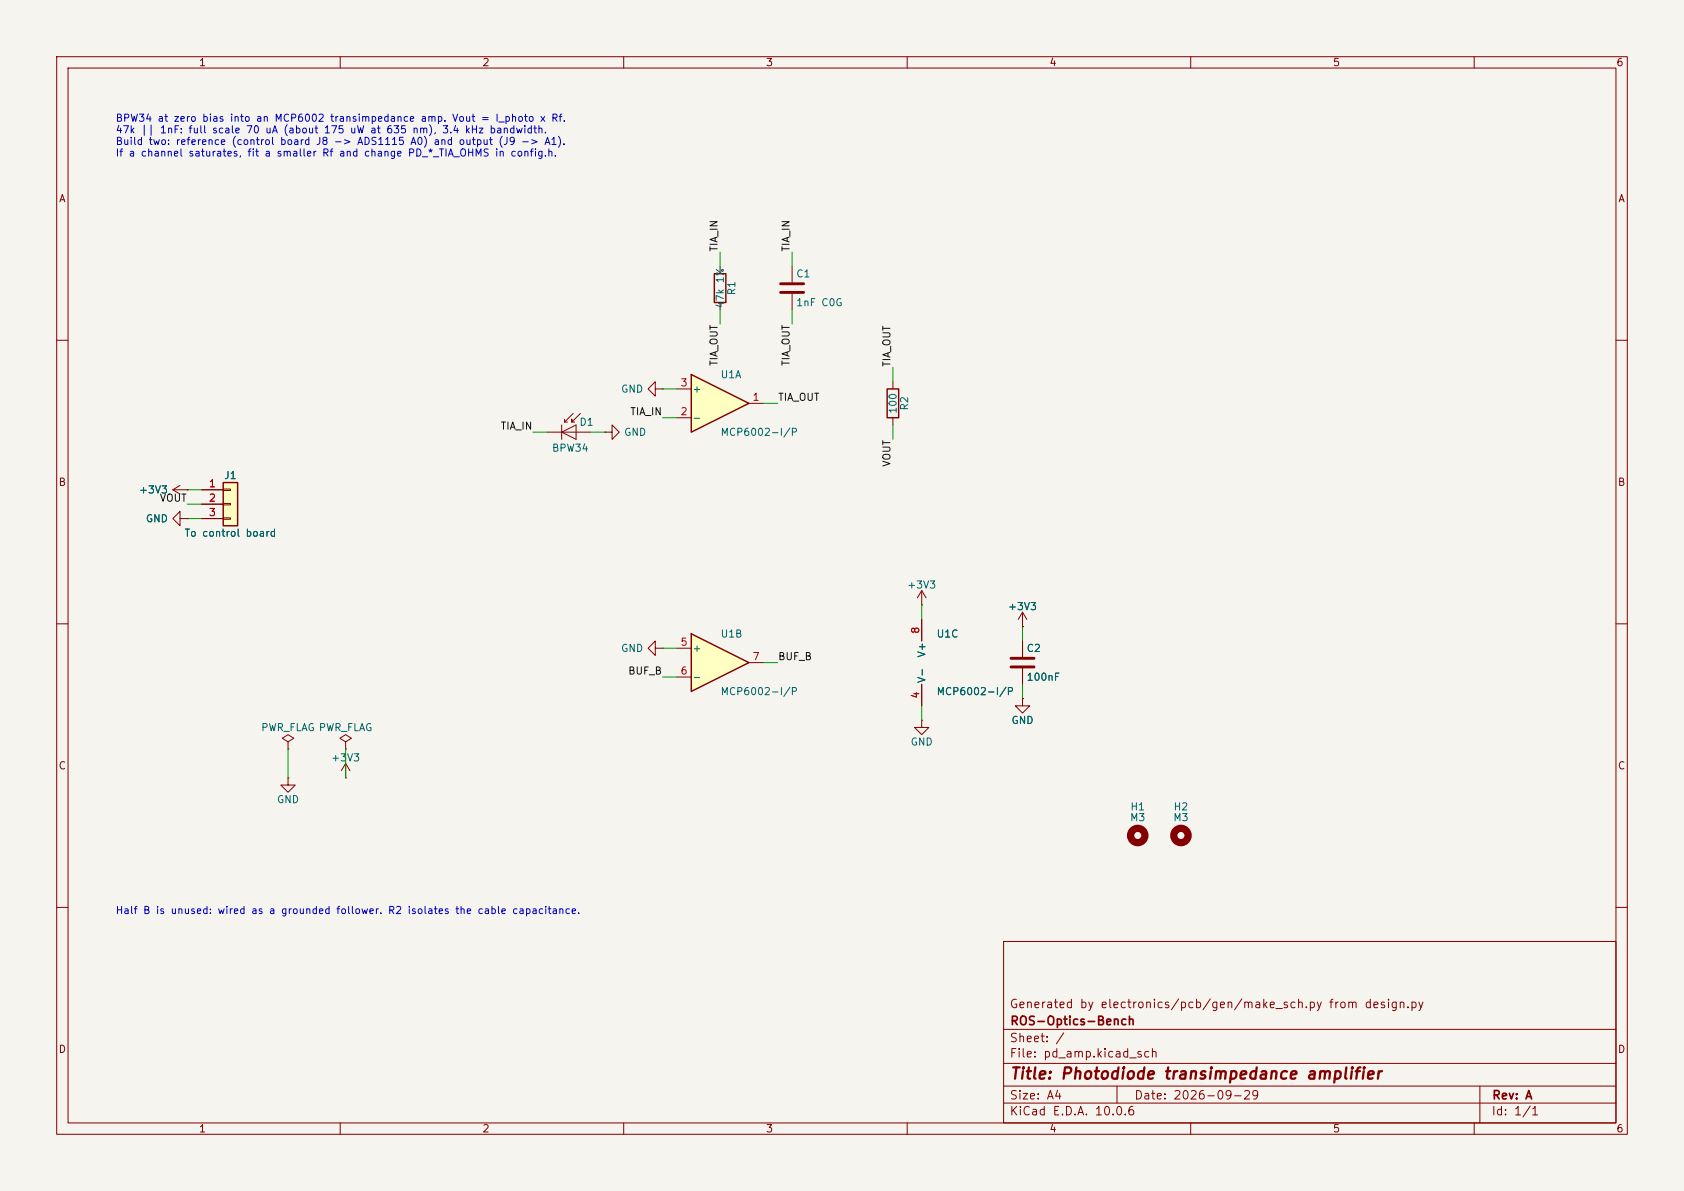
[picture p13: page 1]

BPW34 at zero bias into an MCP6002 transimpedance amp. Vout = I_photo x Rf. 47k || 1nF: full scale 70 uA (about 175 uW at 635 nm), 3.4 kHz bandwidth. Build two: reference (control board J8 -> ADS1115 A0) and output (J9 -> A1).

Half B is unused: wired as a grounded follower. R2 isolates the cable capacitance.

ROS-Optics-Bench
Sheet: /
File: pd_amp.kicad_sch
Title: Photodiode transimpedance amplifier

Size: A4 | Rev: A
KiCad E.D.A. 10.0.6 | Id: 1/1

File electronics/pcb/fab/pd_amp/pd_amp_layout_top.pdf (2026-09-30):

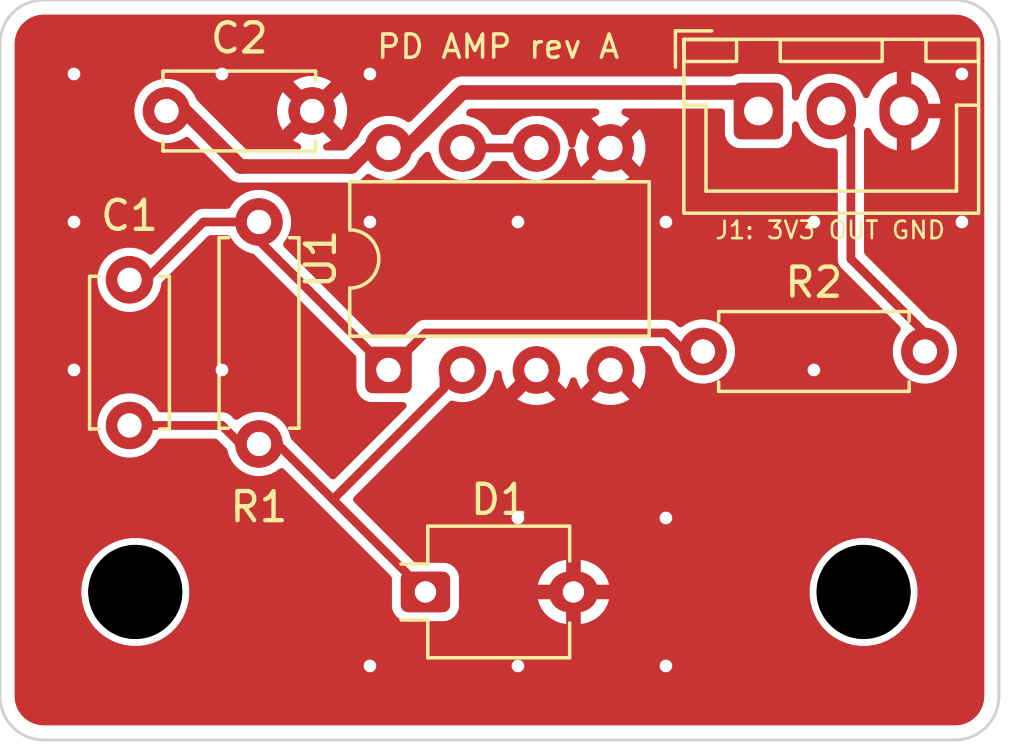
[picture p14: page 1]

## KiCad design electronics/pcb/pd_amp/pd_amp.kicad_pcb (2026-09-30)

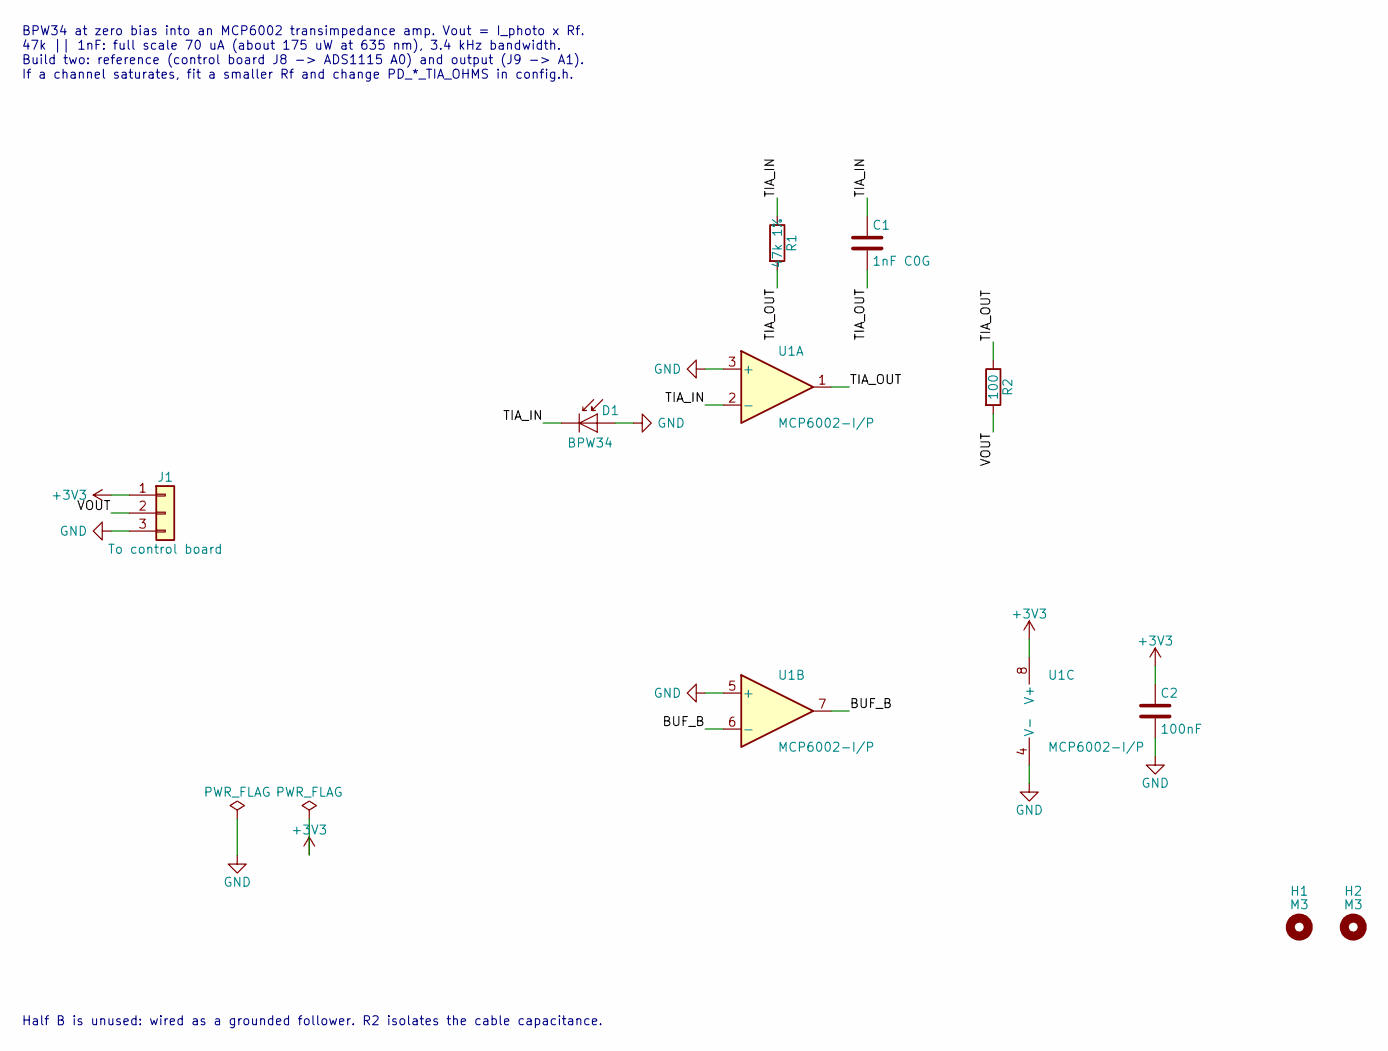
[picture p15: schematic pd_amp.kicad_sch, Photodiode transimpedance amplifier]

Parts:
C1: 1nF C0G; C_Disc_D5.0mm_W2.5mm_P5.00mm
C2: 100nF; C_Disc_D5.0mm_W2.5mm_P5.00mm
D1: BPW34; Osram_DIL2_4.3x4.65mm_P5.08mm
H1, H2: M3; MountingHole_3.2mm_M3
J1: To control board; JST_XH_B3B-XH-A_1x03_P2.50mm_Vertical
R1: 47k 1%; R_Axial_DIN0207_L6.3mm_D2.5mm_P7.62mm_Horizontal
R2: 100; R_Axial_DIN0207_L6.3mm_D2.5mm_P7.62mm_Horizontal
U1: MCP6002-I/P; DIP-8_W7.62mm

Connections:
+3V3: C2.1, J1.1, U1.8 (V+)
/BUF_B: U1.6 (-), U1.7
/TIA_IN: C1.1, D1.1 (K), R1.1, U1.2 (-)
/TIA_OUT: C1.2, R1.2, R2.1, U1.1
/VOUT: J1.2, R2.2
GND: C2.2, D1.2 (A), J1.3, U1.3 (+), U1.4 (V-), U1.5 (+)

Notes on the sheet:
BPW34 at zero bias into an MCP6002 transimpedance amp. Vout = I_photo x Rf. 47k || 1nF: full scale 70 uA (about 175 uW at 635 nm), 3.4 kHz bandwidth. Build two: reference (control board J8 -> ADS1115 A0) and output (J9 -> A1). If a channel saturates, fit a smaller Rf and change PD_*_TIA_OHMS in con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
Half B is unused: wired as a grounded follower. R2 isolates the cable capacitance.

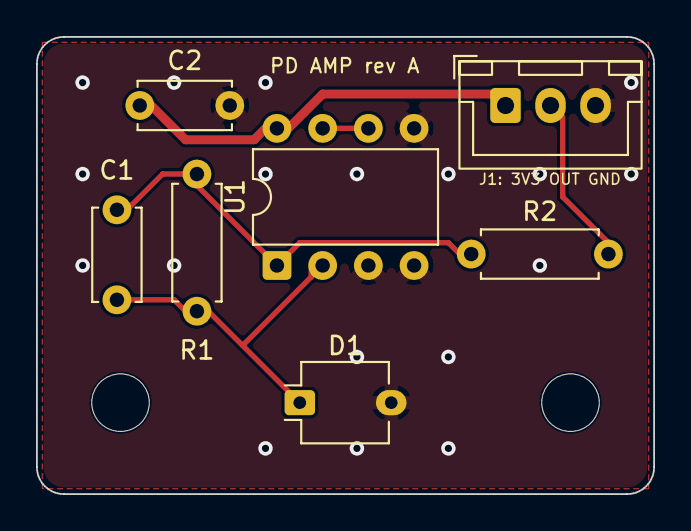
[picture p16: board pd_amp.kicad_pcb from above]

Board: 2 copper layers, 34.3 x 25.4 mm, 9 parts (0 on the bottom side), 6 nets.

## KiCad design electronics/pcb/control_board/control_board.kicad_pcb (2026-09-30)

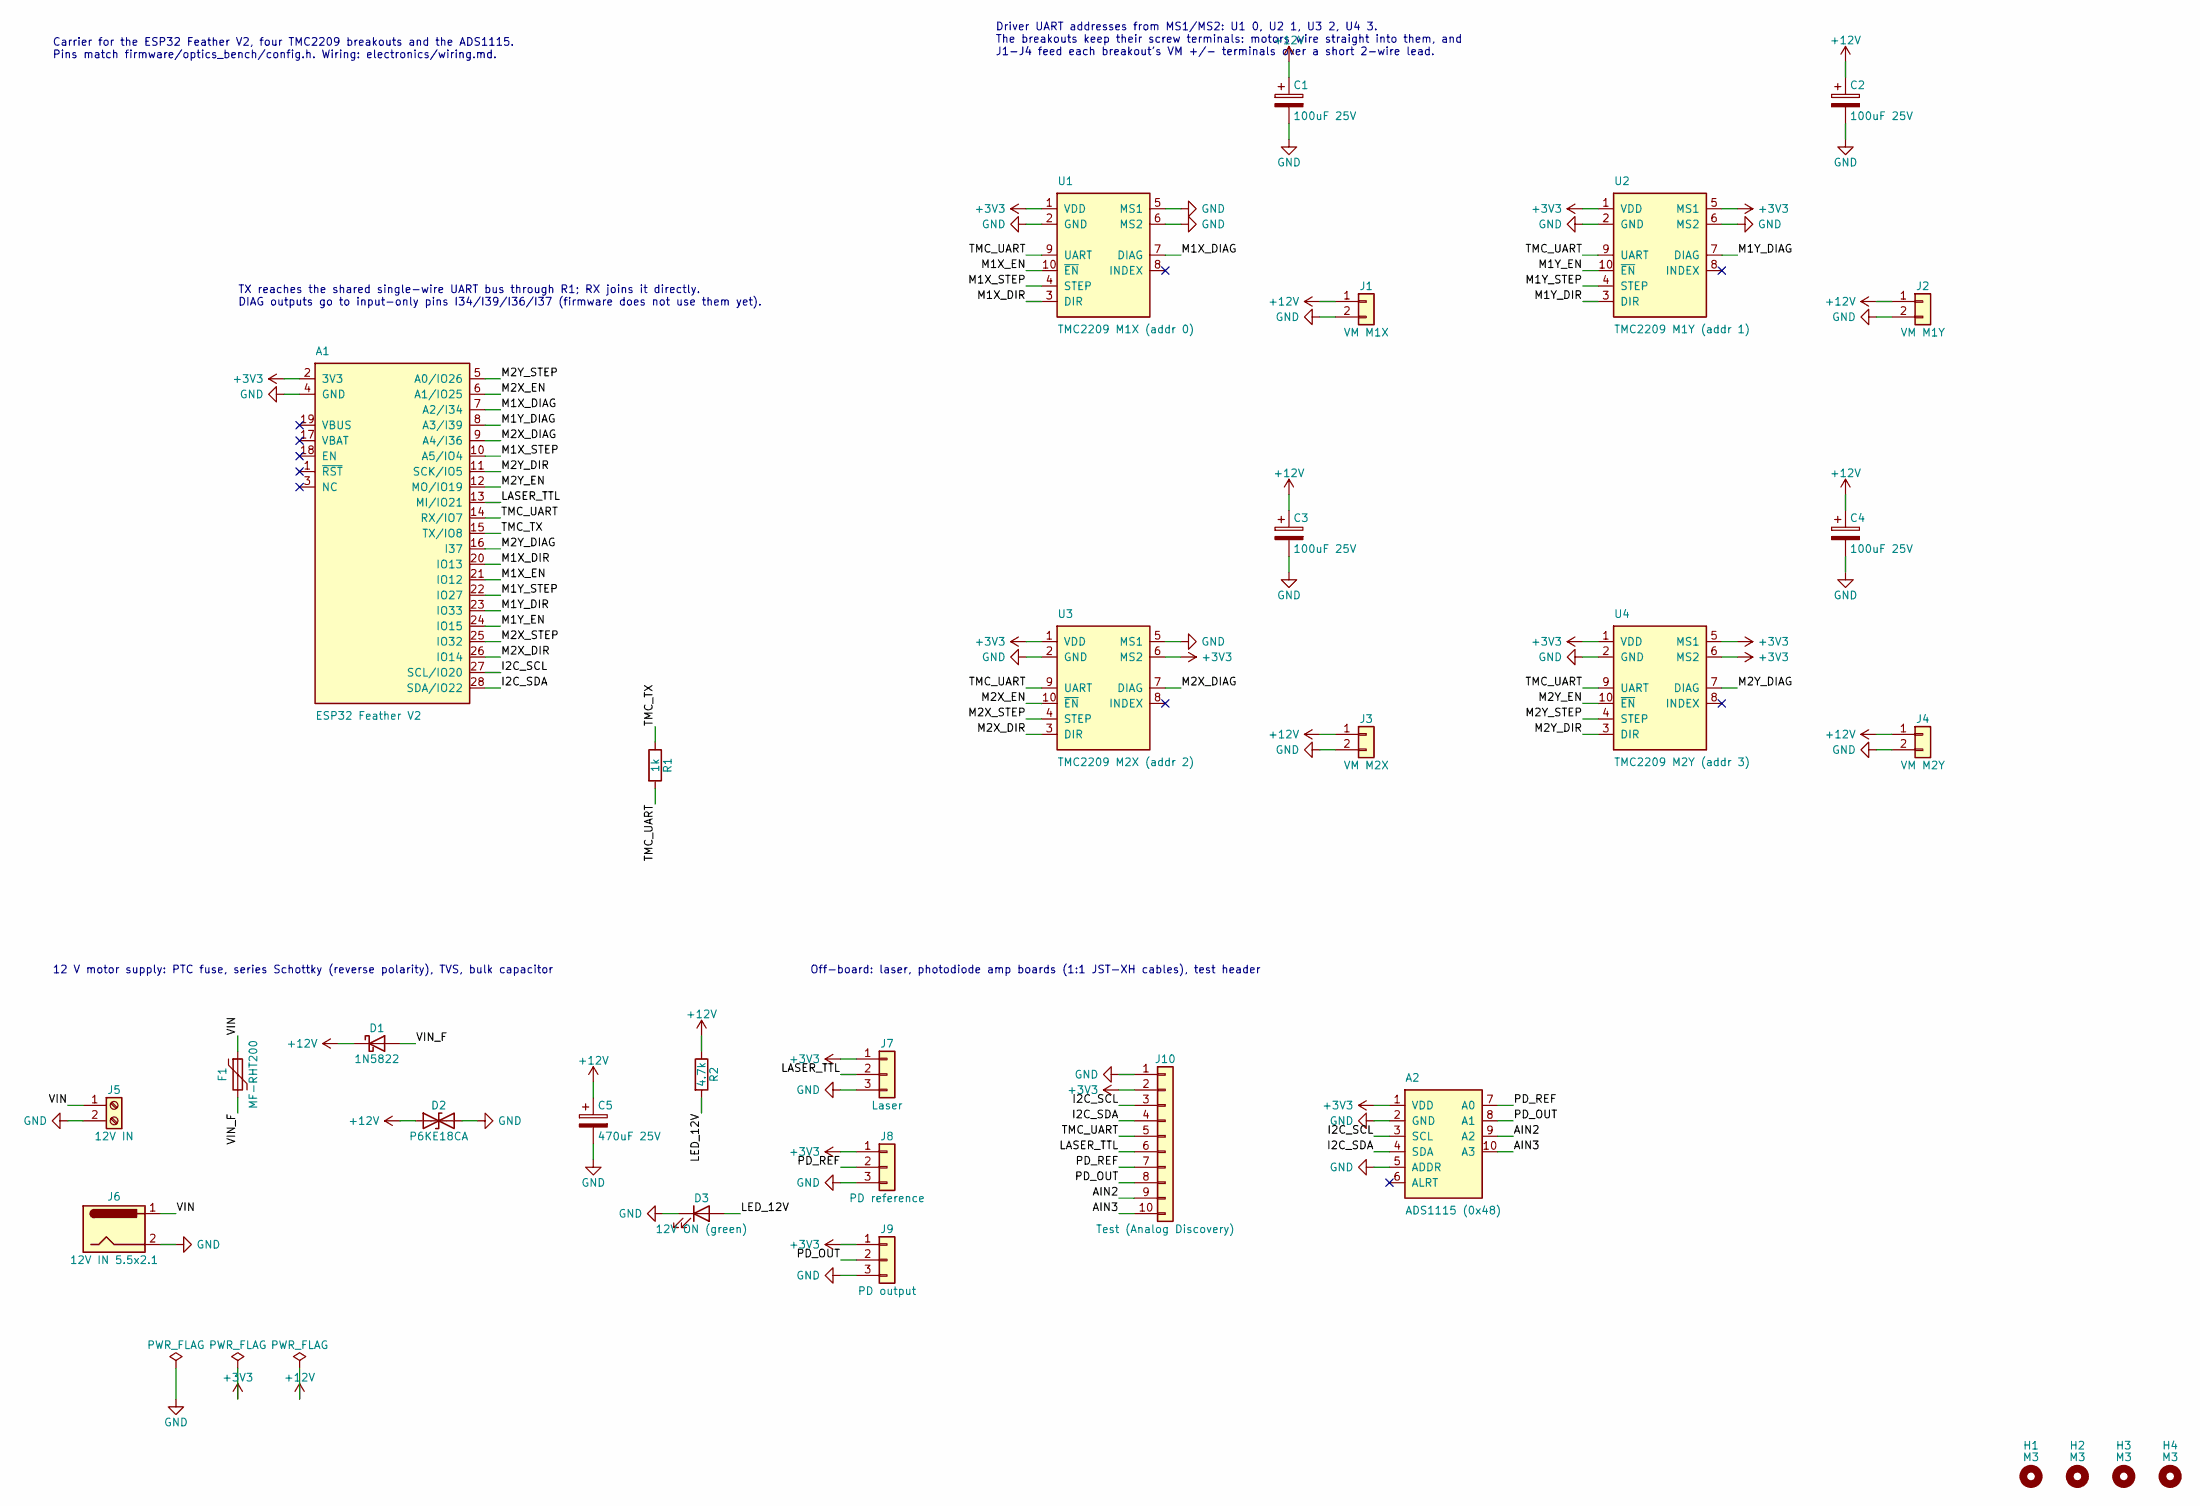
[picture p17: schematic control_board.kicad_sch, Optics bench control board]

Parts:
A1: ESP32 Feather V2; Adafruit_Feather_ESP32_V2_Socket
A2: ADS1115 (0x48); Adafruit_ADS1115_Socket
C1, C2, C3, C4: 100uF 25V; CP_Radial_D6.3mm_P2.50mm
C5: 470uF 25V; CP_Radial_D10.0mm_P5.00mm
D1: 1N5822; D_DO-201AD_P15.24mm_Horizontal
D2: P6KE18CA; D_DO-15_P10.16mm_Horizontal
D3: 12V ON (green); LED_D3.0mm
F1: MF-RHT200; Fuse_Bourns_MF-RHT200
H1, H2, H3, H4: M3; MountingHole_3.2mm_M3
J1: VM M1X; JST_XH_B2B-XH-A_1x02_P2.50mm_Vertical
J2: VM M1Y; JST_XH_B2B-XH-A_1x02_P2.50mm_Vertical
J3: VM M2X; JST_XH_B2B-XH-A_1x02_P2.50mm_Vertical
J4: VM M2Y; JST_XH_B2B-XH-A_1x02_P2.50mm_Vertical
J5: 12V IN; TerminalBlock_Phoenix_MKDS-1,5-2-5.08_1x02_P5.08mm_Horizont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
J6: 12V IN 5.5x2.1; BarrelJack_Horizontal
J7: Laser; JST_XH_B3B-XH-A_1x03_P2.50mm_Vertical
J8: PD reference; JST_XH_B3B-XH-A_1x03_P2.50mm_Vertical
J9: PD output; JST_XH_B3B-XH-A_1x03_P2.50mm_Vertical
J10: Test (Analog Discovery); PinHeader_1x10_P2.54mm_Vertical
R1: 1k; R_Axial_DIN0207_L6.3mm_D2.5mm_P10.16mm_Horizontal
R2: 4.7k; R_Axial_DIN0207_L6.3mm_D2.5mm_P10.16mm_Horizontal
U1: TMC2209 M1X (addr 0); Adafruit_TMC2209_Socket
U2: TMC2209 M1Y (addr 1); Adafruit_TMC2209_Socket
U3: TMC2209 M2X (addr 2); Adafruit_TMC2209_Socket
U4: TMC2209 M2Y (addr 3); Adafruit_TMC2209_Socket

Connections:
+3V3: A1.2 (3V3), A2.1 (VDD), J7.1, J8.1, J9.1, J10.2, U1.1 (VDD), U2.1 (VDD), U2.5 (MS1), U3.1 (VDD), U3.6 (MS2), U4.1 (VDD), U4.5 (MS1), U4.6 (MS2)
+12V: C1.1, C2.1, C3.1, C4.1, C5.1, D1.1 (K), D2.1 (A1), J1.1, J2.1, J3.1, J4.1, R2.1
/AIN2: A2.9 (A2), J10.9
/AIN3: A2.10 (A3), J10.10
/I2C_SCL: A1.27 (SCL/IO20), A2.3 (SCL), J10.3
/I2C_SDA: A1.28 (SDA/IO22), A2.4 (SDA), J10.4
/LASER_TTL: A1.13 (MI/IO21), J7.2, J10.6
/LED_12V: D3.2 (A), R2.2
/M1X_DIAG: A1.7 (A2/I34), U1.7 (DIAG)
/M1X_DIR: A1.20 (IO13), U1.3 (DIR)
/M1X_EN: A1.21 (IO12), U1.10 (~EN)
/M1X_STEP: A1.10 (A5/IO4), U1.4 (STEP)
/M1Y_DIAG: A1.8 (A3/I39), U2.7 (DIAG)
/M1Y_DIR: A1.23 (IO33), U2.3 (DIR)
/M1Y_EN: A1.24 (IO15), U2.10 (~EN)
/M1Y_STEP: A1.22 (IO27), U2.4 (STEP)
/M2X_DIAG: A1.9 (A4/I36), U3.7 (DIAG)
/M2X_DIR: A1.26 (IO14), U3.3 (DIR)
/M2X_EN: A1.6 (A1/IO25), U3.10 (~EN)
/M2X_STEP: A1.25 (IO32), U3.4 (STEP)
/M2Y_DIAG: A1.16 (I37), U4.7 (DIAG)
/M2Y_DIR: A1.11 (SCK/IO5), U4.3 (DIR)
/M2Y_EN: A1.12 (MO/IO19), U4.10 (~EN)
/M2Y_STEP: A1.5 (A0/IO26), U4.4 (STEP)
/PD_OUT: A2.8 (A1), J9.2, J10.8
/PD_REF: A2.7 (A0), J8.2, J10.7
/TMC_TX: A1.15 (TX/IO8), R1.1
/TMC_UART: A1.14 (RX/IO7), J10.5, R1.2, U1.9 (UART), U2.9 (UART), U3.9 (UART), U4.9 (UART)
/VIN: F1.1, J5.1, J6.1
/VIN_F: D1.2 (A), F1.2
GND: A1.4 (GND), A2.2 (GND), A2.5 (ADDR), C1.2, C2.2, C3.2, C4.2, C5.2, D2.2 (A2), D3.1 (K), J1.2, J2.2, J3.2, J4.2, J5.2, J6.2, J7.3, J8.3, J9.3, J10.1, U1.2 (GND), U1.5 (MS1), U1.6 (MS2), U2.2 (GND), U2.6 (MS2), U3.2 (GND), U3.5 (MS1), U4.2 (GND)

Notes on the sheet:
Carrier for the ESP32 Feather V2, four TMC2209 breakouts and the ADS1115. Pins match firmware/optics_bench/config.h. Wiring: electronics/wiring.md.
12 V motor supply: PTC fuse, series Schottky (reverse polarity), TVS, bulk capacitor
Off-board: laser, photodiode amp boards (1:1 JST-XH cables), test header
Driver UART addresses from MS1/MS2: U1 0, U2 1, U3 2, U4 3. The breakouts keep their screw terminals: motors wire straight into them, and J1-J4 feed each breakout's VM +/- terminals over a short 2-wire lead.
TX reaches the shared single-wire UART bus through R1; RX joins it directly. DIAG outputs go to input-only pins I34/I39/I36/I37 (firmware does not use them yet).

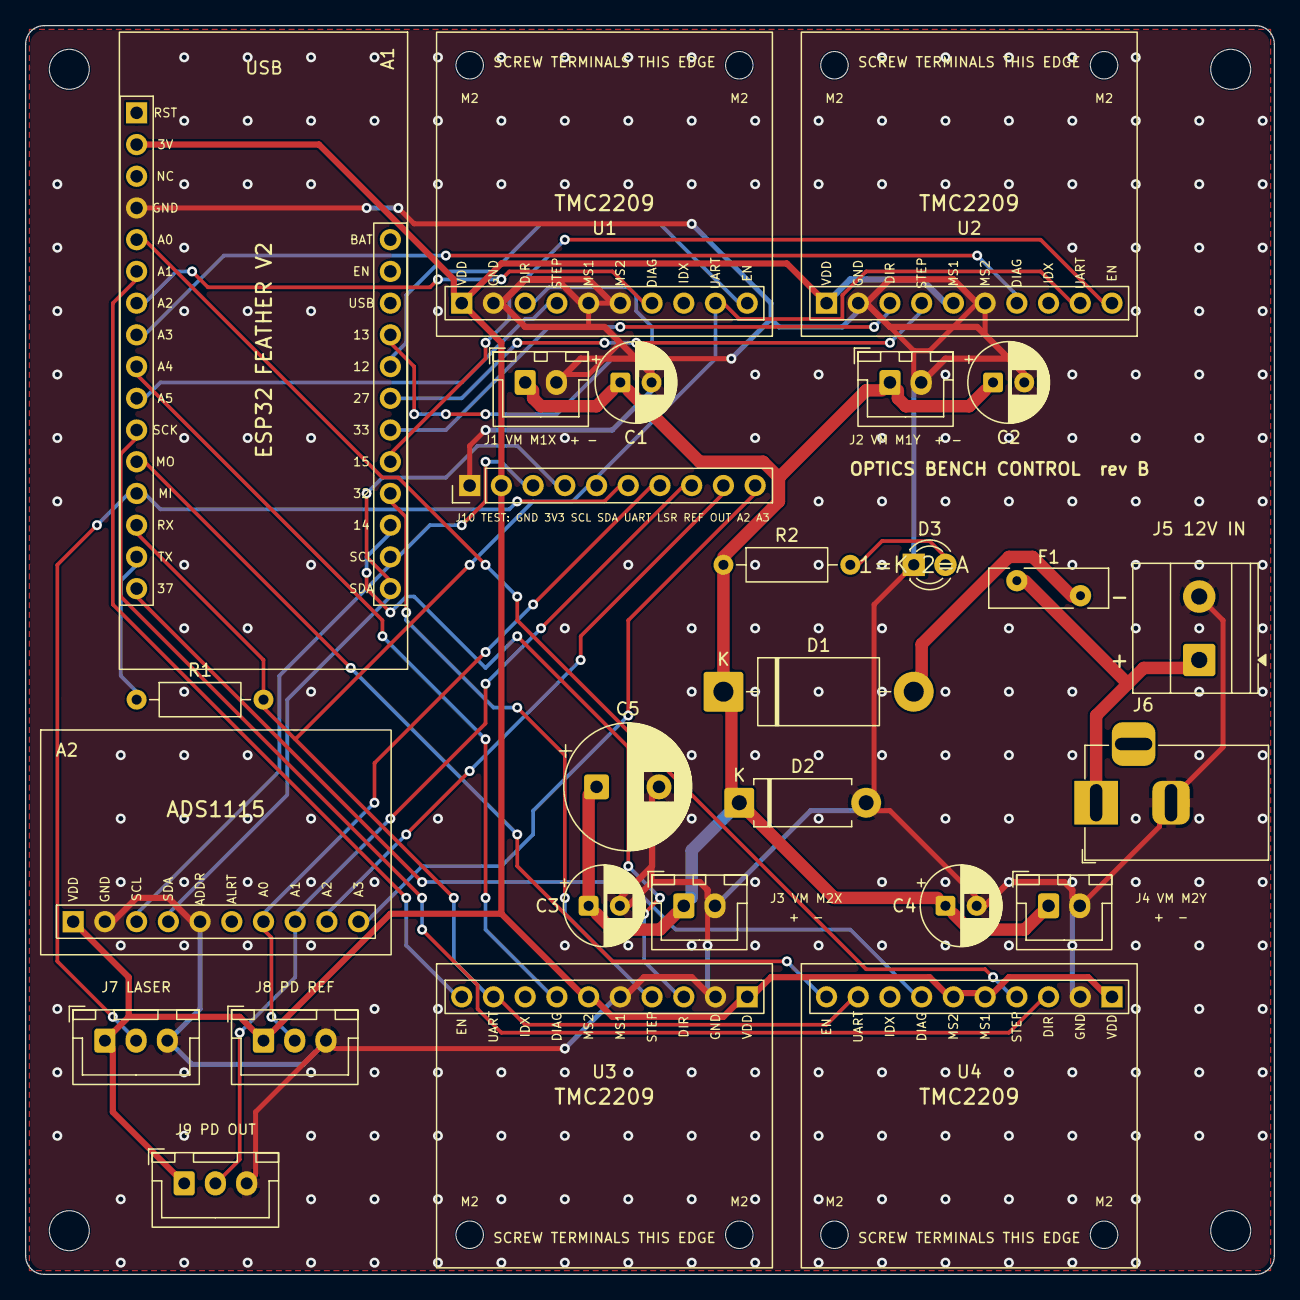
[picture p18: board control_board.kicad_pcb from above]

Board: 2 copper layers, 100.0 x 100.0 mm, 31 parts (0 on the bottom side), 31 nets.

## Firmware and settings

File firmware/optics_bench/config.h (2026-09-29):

#pragma once

// Bench-wide settings: pin map, bus addresses, motor defaults and limits.
// Every pin the firmware touches is set here.
//
// Board: Adafruit ESP32 Feather V2 (product 5400). Drivers: 4x Adafruit
// TMC2209 breakout (product 6121). Laser: Quarton VLM-635-32 LPT.
// Wiring diagram and pin table: electronics/wiring.md.
// M1X/M1Y use the pins of the two TMC2209 slots in the earlier featherv2
// sketch; the rest were picked from the Feather V2's free pads.

#include <Arduino.h>

#define FW_VERSION "0.1.0"

// ── Host serial (USB) ────────────────────────────────────────────────────────
#define SERIAL_BAUD 115200

// ── TMC2209 shared single-wire UART ─────────────────────────────────────────
// All four breakouts' UART pins join on one bus. ESP32 RX goes straight to
// it, ESP32 TX goes to it through a 1 kOhm resistor (the Adafruit breakout
// has no resistor of its own on UART). Each driver gets its own address
// (0-3) from its MS1/MS2 pins, which have no pull resistors on the breakout,
// so tie each one to 3V3 or GND:
//   addr 0: MS1=GND  MS2=GND     addr 1: MS1=3V3  MS2=GND
//   addr 2: MS1=GND  MS2=3V3     addr 3: MS1=3V3  MS2=3V3
#define TMC_SERIAL   Serial1
#define TMC_RX_PIN   7        // Feather V2 RX pad
#define TMC_TX_PIN   8        // Feather V2 TX pad
#define TMC_BAUD     115200
#define R_SENSE      0.05f    // Adafruit 6121 sense resistors (R1/R2). BTT/FYSETC modules use 0.11
#define TMC_EXPECTED_VER 0x21 // IOIN version byte of a TMC2209

// A driver that doesn't answer on the UART runs on its pin-strapped defaults
// (MS1/MS2 then pick 8-64x microstepping, current comes from the VREF pot),
// so moves on that axis are refused. Set true only to spin a motor while the
// UART wiring is being debugged; positions will then be wrong by the
// microstep ratio.
#define ALLOW_MOVES_WITHOUT_UART false

// ── Motor axes ──────────────────────────────────────────────────────────────
// Two motors per mirror: X and Y adjusters on M1 and M2. Which adjuster is
// "X" is up to the wiring; rename here if it reads better another way.
// invert: flips the positive direction in software instead of rewiring.
// EN is active low. The breakout pulls EN low (20k), so a driver is enabled
// until the firmware drives EN high at boot. That pull-down also keeps
// GPIO 12, an ESP32 boot strapping pin, low at reset as it must be.
// GPIO 13 also drives the Feather's red LED, which flickers with M1X DIR.
struct AxisPins {
  const char *name;
  uint8_t step, dir, en;
  uint8_t addr;     // TMC2209 UART address from MS1/MS2
  bool invert;
};

#define NUM_AXES 4
constexpr AxisPins AXIS_PINS[NUM_AXES] = {
  //  name   STEP DIR EN  addr invert
  { "M1X",   4,  13, 12,  0,  false },   // pads A5, 13, 12
  { "M1Y",  27,  33, 15,  1,  false },   // pads 27, 33, 15
  { "M2X",  32,  14, 25,  2,  false },   // pads 32, 14, A1
  { "M2Y",  26,   5, 19,  3,  false },   // pads A0, SCK, MO
};

// On the control board (electronics/pcb) each driver's DIAG output also reaches an
// input-only pin: M1X GPIO 34 (A2), M1Y 39 (A3), M2X 36 (A4), M2Y 37. Not used yet.

// ── Laser ───────────────────────────────────────────────────────────────────
// Quarton VLM-635-32 LPT: 3-6 V supply (< 40 mA, from the Feather's 3V3),
// TTL input high = on, 1-20 mA, so a GPIO drives it directly.
#define LASER_PIN         21      // MI pad
#define LASER_ACTIVE_HIGH true

// ── Photodiodes and ADC ─────────────────────────────────────────────────────
// Two BPW34 photodiodes, each on its own transimpedance amp (MCP6002, one
// half used) run from 3V3, read by an Adafruit ADS1115 (product 1085) on the
// Feather's I2C pads. The Feather V2 powers its STEMMA QT port from GPIO 2,
// which the board package switches on before setup().
//   AIN0: reference photodiode (beamsplitter's reflected port)
//   AIN1: output photodiode (behind the fiber)
// Vout = I_photo x feedback resistor, so 47 kOhm puts the full 3.3 V swing
// at 70 uA, about 175 uW of 635 nm light on a BPW34 (the laser is < 1 mW).
// The ADS1115's own gain ranges (+-4.096 V down to +-0.256 V) cover the dim
// end: 1 LSB at the finest range is 7.8 uV, about 0.4 nW. If a channel sits
// near 3.3 V, fit a smaller resistor on that board and change it here; the
// GUI turns volts into uW with these values.
#define I2C_SDA_PIN     22
#define I2C_SCL_PIN     20
#define I2C_CLOCK_HZ    400000
#define ADS1115_ADDR    0x48      // ADDR pin to GND
#define PD_REF_CHANNEL  0
#define PD_OUT_CHANNEL  1
#define PD_REF_TIA_OHMS 47000.0f  // feedback resistor, reference TIA board
#define PD_OUT_TIA_OHMS 47000.0f  // feedback resistor, output TIA board
#define PD_RESPONSIVITY 0.40f     // BPW34 at 635 nm, A/W (datasheet curve, approximate)
#define PD_DARK_SAMPLES 32        // samples per channel for PD DARK
#define PD_SETTLE_MS    30        // after switching the laser, before sampling
#define PD_MAX_STREAM_HZ 50

// ── Stepping ────────────────────────────────────────────────────────────────
// NEMA 8, 1.8 deg. The driver interpolates every setting to 256x internally
// (intpol), so 16x is as smooth as it gets while keeping pulse rates low.
// Positions on the serial protocol are in microsteps at this setting.
#define FULL_STEPS_PER_REV 200
#define MICROSTEPS         16
#define USTEPS_PER_REV     (FULL_STEPS_PER_REV * MICROSTEPS)   // 3200

// Motor current. The 8HS15-0604S class is rated 0.6 A per phase; 350 mA RMS
// is about 0.5 A peak. Hold current is a fraction of run current and kicks
// in ~0.2 s after the last step (TPOWERDOWN).
#define RUN_CURRENT_MA   350
#define MAX_CURRENT_MA   420      // ceiling for the CURRENT command
#define HOLD_MULTIPLIER  0.5f

// Speeds in adjuster turns per minute (= motor RPM, direct drive).
// A 100 TPI adjuster moves 0.254 mm per turn.
#define DEFAULT_RPM       30.0f
#define MAX_RPM          120.0f   // 120 RPM x 3200 = 6.4 kHz STEP per axis
#define DEFAULT_ACCEL_RPM_S 120.0f  // RPM gained per second

#define ENABLE_SETTLE_MS 180      // StealthChop standstill calibration after EN low

// Coil release, as in the featherv2 sketch: a motor is energised for a move
// and released (EN high, no coil current) once it has been still for
// RELEASE_DELAY_MS, so the motors don't sit warm between moves. The 100 TPI
// adjuster screws don't back-drive, so the mirror stays put. The delay keeps
// a burst of nudges from paying the enable settle on every one. ENABLE holds
// a motor energised until DISABLE. Set AUTO_RELEASE false to keep motors
// energised (at hold current) after every move instead.
#define AUTO_RELEASE     true
#define RELEASE_DELAY_MS 500

// ── Soft limits ─────────────────────────────────────────────────────────────
// The CAD check found only ~4 turns of hex engagement one way and ~8 the
// other before the bit bottoms out or pulls out of the adjuster. Limits are
// relative to the zero position (ZERO command) and stored in flash with it.
// ABS_LIMIT_TURNS caps what the LIMITS command will accept.
#define DEFAULT_MIN_TURNS -3.0f
#define DEFAULT_MAX_TURNS  3.0f
#define ABS_LIMIT_TURNS    8.0f

// ── Host safety ─────────────────────────────────────────────────────────────
// A continuous JOG stops unless the host repeats it within this window, so a
// crashed GUI can't leave a motor running to its limit.
#define JOG_TIMEOUT_MS 400

// Positions are written to flash this long after all motion stops.
#define POS_SAVE_DELAY_MS 1000

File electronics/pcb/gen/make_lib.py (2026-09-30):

"""Write lib/optics_bench.kicad_sym and lib/optics_bench.pretty (plug-in breakout sockets).

Usage: py -3 electronics/pcb/gen/make_lib.py
"""
import os

from design import SYMBOLS
from sexp import Sym, dump

HERE = os.path.dirname(os.path.abspath(__file__))
LIB = os.path.join(HERE, "..", "lib")
S = Sym


def font(size=1.27, hide=False, justify=None):
    e = [S("effects"), [S("font"), [S("size"), size, size]]]
    if justify:
        e.append([S("justify"), *[S(j) for j in justify.split()]])
    out = [e]
    if hide:
        out.insert(0, [S("hide"), S("yes")])
    return out


def prop(name, value, x, y, hide=False, justify=None):
    return [S("property"), name, value, [S("at"), x, y, 0], *font(hide=hide, justify=justify)]


def pin(num, name, etype, x, y, rot):
    return [S("pin"), S(etype), S("line"), [S("at"), x, y, rot], [S("length"), 2.54],
            [S("name"), name, *font()], [S("number"), num, *font()]]


def pin_rows(spec):
    rows = max(len(spec["left"]), len(spec["right"]))
    top = ((rows - 1) // 2 + 1) * 2.54
    return rows, top


def symbol(name, spec):
    rows, top = pin_rows(spec)
    hw = spec["width"] / 2
    bottom = top - (rows + 1) * 2.54
    pins = []
    for col, x, rot in ((spec["left"], -hw - 2.54, 0), (spec["right"], hw + 2.54, 180)):
        for i, p in enumerate(col):
            if p:
                pins.append(pin(p[0], p[1], p[2], x, round(top - (i + 1) * 2.54, 3), rot))
    body = [S("rectangle"), [S("start"), -hw, top], [S("end"), hw, bottom],
            [S("stroke"), [S("width"), 0.254], [S("type"), S("default")]], [S("fill"), [S("type"), S("background")]]]
    return [S("symbol"), name, [S("pin_names"), [S("offset"), 1.016]],
            [S("exclude_from_sim"), S("no")], [S("in_bom"), S("yes")], [S("on_board"), S("yes")],
            prop("Reference", spec["ref"], -hw, top + 1.27, justify="left bottom"),
            prop("Value", name.replace("_", " "), -hw, bottom - 1.27, justify="left top"),
            prop("Footprint", spec["footprint"], 0, bottom - 3.81, hide=True),
            prop("Datasheet", "", 0, 0, hide=True),
            prop("Description", spec["descr"], 0, 0, hide=True),
            [S("symbol"), f"{name}_0_1", body],
            [S("symbol"), f"{name}_1_1", *pins],
            [S("embedded_fonts"), S("no")]]


def write_symbols():
    lib = [S("kicad_symbol_lib"), [S("version"), 20251024], [S("generator"), "optics_bench_gen"],
           [S("generator_version"), "10.0"]]
    lib += [symbol(n, s) for n, s in SYMBOLS.items()]
    with open(os.path.join(LIB, "optics_bench.kicad_sym"), "w", encoding="utf8", newline="\n") as f:
        f.write(dump(lib) + "\n")


# ── Footprints ──────────────────────────────────────────────────────────────

def fp_text(kind, text, x, y, layer, size=1.0, hide=False):
    p = [S("property"), kind, text, [S("at"), x, y, 0], [S("layer"), layer]]
    if hide:
        p.append([S("hide"), S("yes")])
    p.append([S("effects"), [S("font"), [S("size"), size, size], [S("thickness"), round(size * 0.15, 3)]]])
    return p


def gr_text(text, x, y, layer, size=1.0, rot=0):
    return [S("fp_text"), S("user"), text, [S("at"), x, y, rot], [S("layer"), layer],
            [S("effects"), [S("font"), [S("size"), size, size], [S("thickness"), round(size * 0.15, 3)]]]]


def line(x1, y1, x2, y2, layer, w=0.12):
    return [S("fp_line"), [S("start"), x1, y1], [S("end"), x2, y2],
            [S("stroke"), [S("width"), w], [S("type"), S("solid")]], [S("layer"), layer]]


def rect(x1, y1, x2, y2, layer, w=0.12):
    return [S("fp_rect"), [S("start"), x1, y1], [S("end"), x2, y2],
            [S("stroke"), [S("width"), w], [S("type"), S("solid")]], [S("fill"), S("no")], [S("layer"), layer]]


def tht_pad(num, x, y, square=False):
    return [S("pad"), num, S("thru_hole"), S("rect") if square else S("circle"), [S("at"), x, y],
            [S("size"), 1.7, 1.7], [S("drill"), 1.0], [S("layers"), "*.Cu", "*.Mask"],
            [S("remove_unused_layers"), S("no")]]


def socket_strip(x0, y0, n, dx, layer="F.SilkS"):
    """Silk box around a straight row of n pins starting at (x0, y0) going dx per pin."""
    xs = [x0 + i * dx for i in range(n)]
    return rect(min(xs) - 1.33, y0 - 1.33, max(xs) + 1.33, y0 + 1.33, layer)


def npth(x, y, d):
    return [S("pad"), "", S("np_thru_hole"), S("circle"), [S("at"), x, y], [S("size"), d, d],
            [S("drill"), d], [S("layers"), "*.Cu", "*.Mask"]]


def socket_model(n, x, y, direction):
    """KiCad's 1xN female header 3D model, pin 1 at (x, y), row running along +x or -x."""
    path = f"${{KICAD10_3DMODEL_DIR}}/Connector_PinSocket_2.54mm.3dshapes/PinSocket_1x{n:02d}_P2.54mm_Vertical.step"
    return [S("model"), path, [S("offset"), [S("xyz"), x, -y, 0]], [S("scale"), [S("xyz"), 1, 1, 1]],
            [S("rotate"), [S("xyz"), 0, 0, -90 if direction > 0 else 90]]]


def footprint(name, descr, pads, body, labels, extra=(), models=()):
    x1, y1, x2, y2 = body
    fp = [S("footprint"), name, [S("version"), 20260206], [S("generator"), "optics_bench_gen"],
          [S("layer"), "F.Cu"], [S("descr"), descr], [S("tags"), "socket breakout adafruit"],
          fp_text("Reference", "REF**", x1 + 2.0, y1 + 1.5, "F.SilkS"),
          fp_text("Value", name, (x1 + x2) / 2, y2 - 1.2, "F.Fab"),
          [S("attr"), S("through_hole")],
          rect(x1, y1, x2, y2, "F.Fab", 0.1),
          rect(x1 - 0.25, y1 - 0.25, x2 + 0.25, y2 + 0.25, "F.CrtYd", 0.05),
          rect(x1 - 0.11, y1 - 0.11, x2 + 0.11, y2 + 0.11, "F.SilkS", 0.12)]
    fp += list(extra)
    for (txt, x, y, rot, size) in labels:
        fp.append(gr_text(txt, x, y, "F.SilkS", size, rot))
    fp += pads
    fp.append([S("embedded_fonts"), S("no")])
    fp += list(models)
    return fp


def feather_socket():
    row16 = ["RST", "3V", "NC", "GND", "A0", "A1", "A2", "A3", "A4", "A5", "SCK", "MO", "MI", "RX", "TX", "37"]
    row12 = ["BAT", "EN", "USB", "13", "12", "27", "33", "15", "32", "14", "SCL", "SDA"]
    pads = [tht_pad(str(i + 1), i * 2.54, 0, i == 0) for i in range(16)]
    pads += [tht_pad(str(17 + i), 10.16 + i * 2.54, -20.32) for i in range(12)]
    labels = [(t, i * 2.54, -2.3, 90, 0.7) for i, t in enumerate(row16)]
    labels += [(t, 10.16 + i * 2.54, -18.0, 90, 0.7) for i, t in enumerate(row12)]
    labels += [("ESP32 FEATHER V2", 19.0, -10.2, 0, 1.2), ("USB", -3.6, -10.2, 90, 1.0)]
    extra = [socket_strip(0, 0, 16, 2.54), socket_strip(10.16, -20.32, 12, 2.54)]
    return footprint("Adafruit_Feather_ESP32_V2_Socket",
                     "Adafruit ESP32 Feather V2 (5400) on 16- and 12-pin female headers. Pad 1 = RST, "
                     "USB end at the left. Outline is the Feather board.",
                     pads, (-6.35, -21.59, 44.45, 1.27), labels, extra,
                     [socket_model(16, 0, 0, 1), socket_model(12, 10.16, -20.32, 1)])


def tmc_socket():
    # Seen from the top with the logic header along the top edge (Adafruit 6121 rotated 180 deg).
    # Only the logic header plugs in: the breakout keeps its screw terminals, which sit along the
    # far edge. Two M2 holes line up with the breakout's terminal-end mounting holes for standoffs.
    logic = ["VDD", "GND", "DIR", "STEP", "MS1", "MS2", "DIAG", "IDX", "UART", "EN"]
    pads = [tht_pad(str(i + 1), -i * 2.54, 0, i == 0) for i in range(10)]
    pads += [npth(-0.635, 19.05, 2.2), npth(-22.225, 19.05, 2.2)]
    labels = [(t, -i * 2.54, 2.4, 90, 0.7) for i, t in enumerate(logic)]
    labels += [("TMC2209", -11.43, 8.0, 0, 1.2), ("M2", -0.635, 16.4, 0, 0.7), ("M2", -22.225, 16.4, 0, 0.7),
               ("SCREW TERMINALS THIS EDGE", -11.43, 19.3, 0, 0.8)]
    extra = [socket_strip(0, 0, 10, -2.54)]
    return footprint("Adafruit_TMC2209_Socket",
                     "Adafruit TMC2209 breakout (6121) on a 10-pin female header, screw terminals kept on the "
                     "breakout at the far edge. M2 standoff holes under its terminal-end mounting holes. "
                     "Outline is the breakout.",
                     pads, (-24.765, -2.54, 1.905, 21.59), labels, extra,
                     [socket_model(10, 0, 0, -1)])


def ads_socket():
    names = ["VDD", "GND", "SCL", "SDA", "ADDR", "ALRT", "A0", "A1", "A2", "A3"]
    pads = [tht_pad(str(i + 1), i * 2.54, 0, i == 0) for i in range(10)]
    labels = [(t, i * 2.54, -2.6, 90, 0.7) for i, t in enumerate(names)]
    labels += [("ADS1115", 11.43, -9.0, 0, 1.2)]
    extra = [socket_strip(0, 0, 10, 2.54)]
    return footprint("Adafruit_ADS1115_Socket",
                     "Adafruit ADS1115 breakout (1085) on a 10-pin female header, board above the header.",
                     pads, (-2.49, -15.24, 25.35, 2.54), labels, extra, [socket_model(10, 0, 0, 1)])


def write_footprints():
    d = os.path.join(LIB, "optics_bench.pretty")
    os.makedirs(d, exist_ok=True)
    for fp in (feather_socket(), tmc_socket(), ads_socket()):
        with open(os.path.join(d, fp[1] + ".kicad_mod"), "w", encoding="utf8", newline="\n") as f:
            f.write(dump(fp) + "\n")


if __name__ == "__main__":
    os.makedirs(LIB, exist_ok=True)
    write_symbols()
    write_footprints()
    print("wrote", os.path.normpath(LIB))

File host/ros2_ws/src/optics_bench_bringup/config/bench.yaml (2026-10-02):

# Parameters for the bench driver (optics_bench_driver/driver_node.py).
# port, sim_fiber and calibration_file can be overridden from the launch command line.
/bench/bench_driver:
  ros__parameters:
    baud: 115200
    sim_seed: -1                # -1: a different simulated bench every start
    status_hz: 5.0              # STATUS poll rate
    pd_hz: 10.0                 # photodiode stream rate while not aligning (max 50)

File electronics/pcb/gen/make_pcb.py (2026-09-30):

"""Build <board>/<board>.kicad_pcb from the schematic netlist and design.py placement, route it
and pour the ground planes.

Run with KiCad's Python (it has pcbnew and numpy), after make_sch.py and a netlist export:
  kicad-cli sch export netlist --format kicadsexpr -o <board>/<board>.net <board>/<board>.kicad_sch
  "<KiCad>/bin/python.exe" electronics/pcb/gen/make_pcb.py [board ...]
build.py runs the whole chain.
"""
import math
import os
import sys
import time

HERE = os.path.dirname(os.path.abspath(__file__))
sys.path.insert(0, HERE)

import pcbnew  # noqa: E402

import design  # noqa: E402
from make_sch import write_project, KICAD  # noqa: E402
from route import Router, Shape  # noqa: E402
from sexp import find, find_all, parse  # noqa: E402

PCB_DIR = os.path.normpath(os.path.join(HERE, ".."))
FP_DIR = os.path.join(KICAD, "share", "kicad", "footprints")
MM = pcbnew.FromMM

# Routing widths and clearances by net (mm). GND is not routed: both layers are ground pours.
POWER = {"+12V", "/VIN", "/VIN_F"}


def net_rule(net):
    if net == "GND":
        return 0.4, 0.2
    if net in POWER:
        return 1.0, 0.3
    if net.startswith("/M") and net[-3:] in ("_1A", "_1B", "_2A", "_2B"):
        return 0.6, 0.25
    if net == "+3V3":
        return 0.5, 0.2
    return 0.3, 0.2


def load_netlist(path):
    with open(path, encoding="utf8") as f:
        t = parse(f.read())
    comps = {}
    for c in find_all(find(t, "components"), "comp"):
        ref = find(c, "ref")[1]
        fields = {}
        for fl in find_all(find(c, "fields") or [], "field"):
            key = find(fl, "name")[1]
            if key != "Footprint" and not key.startswith("ki_"):
                fields[key] = fl[2] if len(fl) > 2 else ""
        comps[ref] = dict(value=find(c, "value")[1], footprint=find(c, "footprint")[1],
                          tstamp=find(c, "tstamps")[1], fields=fields)
    pinnet = {}
    for n in find_all(find(t, "nets"), "net"):
        name = find(n, "name")[1]
        for nd in find_all(n, "node"):
            pinnet[(find(nd, "ref")[1], find(nd, "pin")[1])] = name
    return comps, pinnet


def load_fp(fpid):
    lib, name = fpid.split(":")
    path = (os.path.join(PCB_DIR, "lib", "optics_bench.pretty") if lib == "optics_bench"
            else os.path.join(FP_DIR, lib + ".pretty"))
    fp = pcbnew.FootprintLoad(path, name)
    if fp is None:
        raise FileNotFoundError(fpid)
    fp.SetFPID(pcbnew.LIB_ID(lib, name))
    return fp


def pt(x, y):
    return pcbnew.VECTOR2I(MM(float(x)), MM(float(y)))


def pad_shape(pad, net):
    pos = pad.GetPosition()
    cx, cy = pos.x / 1e6, pos.y / 1e6
    size = pad.GetSize(pcbnew.F_Cu) if hasattr(pad, "GetSize") else pad.GetSize()
    sx, sy = size.x / 1e6, size.y / 1e6
    shape = pad.GetShape(pcbnew.F_Cu)
    ang = pad.GetOrientation().AsRadians()
    tht = pad.GetAttribute() in (pcbnew.PAD_ATTRIB_PTH, pcbnew.PAD_ATTRIB_NPTH)
    layers = (0, 1) if tht else ((0,) if pad.IsOnLayer(pcbnew.F_Cu) else (1,))
    _, clr = net_rule(net) if net else (0, 0.2)
    if shape == pcbnew.PAD_SHAPE_CIRCLE or (shape == pcbnew.PAD_SHAPE_OVAL and abs(sx - sy) < 1e-3):
        return Shape("circle", net, layers, clr, cx=cx, cy=cy, r=max(sx, sy) / 2, drill=tht)
    # KiCad angles are clockwise-positive on screen (y down) -> use -ang in the rect's frame
    return Shape("rect", net, layers, clr, cx=cx, cy=cy, hx=sx / 2, hy=sy / 2, angle=-ang, drill=tht)


def edge_rect(board, w, h, r=1.5):
    """Board outline with rounded corners."""
    def seg(a, b):
        s = pcbnew.PCB_SHAPE(board)
        s.SetShape(pcbnew.SHAPE_T_SEGMENT)
        s.SetStart(pt(*a))
        s.SetEnd(pt(*b))
        s.SetLayer(pcbnew.Edge_Cuts)
        s.SetWidth(MM(0.1))
        board.Add(s)

    def arc(c, start, end):
        s = pcbnew.PCB_SHAPE(board)
        s.SetShape(pcbnew.SHAPE_T_ARC)
        s.SetCenter(pt(*c))
        s.SetStart(pt(*start))
        s.SetEnd(pt(*end))
        s.SetLayer(pcbnew.Edge_Cuts)
        s.SetWidth(MM(0.1))
        board.Add(s)

    seg((r, 0), (w - r, 0))
    seg((w, r), (w, h - r))
    seg((w - r, h), (r, h))
    seg((0, h - r), (0, r))
    arc((w - r, r), (w - r, 0), (w, r))
    arc((w - r, h - r), (w, h - r), (w - r, h))
    arc((r, h - r), (r, h), (0, h - r))
    arc((r, r), (0, r), (r, 0))


def silk_text(board, text, x, y, size=1.0, rot=0, layer=None, bold=False):
    layer = pcbnew.F_SilkS if layer is None else layer
    t = pcbnew.PCB_TEXT(board)
    t.SetText(text)
    t.SetPosition(pt(x, y))
    t.SetLayer(layer)
    t.SetTextSize(pcbnew.VECTOR2I(MM(size), MM(size)))
    t.SetTextThickness(MM(size * (0.2 if bold else 0.15)))
    t.SetTextAngleDegrees(rot)
    if layer == pcbnew.B_SilkS:
        t.SetMirrored(True)
    board.Add(t)


def gnd_zone(board, net, layer, w, h, inset=0.3):
    z = pcbnew.ZONE(board)
    z.SetLayer(layer)
    z.SetNet(net)
    o = z.Outline()
    o.NewOutline()
    for x, y in ((inset, inset), (w - inset, inset), (w - inset, h - inset), (inset, h - inset)):
        o.Append(MM(x), MM(y))
    z.SetLocalClearance(MM(0.3))
    z.SetMinThickness(MM(0.25))
    z.SetThermalReliefGap(MM(0.4))
    z.SetThermalReliefSpokeWidth(MM(0.5))
    z.SetPadConnection(pcbnew.ZONE_CONNECTION_THERMAL)
    z.SetIslandRemovalMode(pcbnew.ISLAND_REMOVAL_MODE_ALWAYS)
    z.SetZoneName(f"GND_{'F' if layer == pcbnew.F_Cu else 'B'}")
    board.Add(z)
    return z
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

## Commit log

2026-09-27 Lay out the repository: README, ESP32 firmware skeleton, CAD folders (#1)
    Adds a project README with the bench layout drawing, a PlatformIO project for the ESP32 (motion, sensing and comms libraries), a ROS 2 workspace folder for the Jetson, and cad/ folders for Onshape ST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
2026-09-27 Switch the ESP32 firmware from PlatformIO to an Arduino IDE sketch (#2)
    Replaces firmware/esp32 (PlatformIO) with firmware/optics_bench, a sketch folder that opens directly in the Arduino IDE: optics_bench.ino, config.h, and src/ folders for motion, sensing and comms. Updates the README folder map and build steps.
    [config.h, optics_bench.ino]
2026-09-28 Add a bill of materials for the NEMA 8 build (#4)
    docs/bom/bom.csv is the diffable source; tools/make_bom_md.py renders docs/bom/README.md with a short NEMA 11 alternate section.
    [bom.csv]
2026-09-29 Bench test firmware and GUI for the laser, mirror motors and photodiodes (#3)
    Bench test firmware for the ESP32 Feather V2 (four TMC2209 axes on one UART bus, laser, ADS1115 photodiode sensing), the PySide6 dark-mode test panel in tools/test_gui.py, and the wiring diagram and 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
2026-09-29 Add KiCad control board and photodiode amp PCBs with system wiring (#5)
    Control board (100 x 100 mm, 2 layers) carrying the ESP32 Feather V2, four TMC2209 breakouts and the ADS1115 on sockets, with 12 V input protection, JST-XH plugs and an Analog Discovery test header. 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
    [bom.csv, control_board.kicad_pcb, control_board.kicad_sch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]
2026-09-30 Keep the TMC2209 screw terminals on the control board (#6)
    The breakouts plug in by their 10-pin logic header only and keep their screw terminals, which face the top and bottom board edges. Motors wire straight into the breakouts; J1-J4 feed each driver's VM over a short lead. M2 standoff holes under each breakout's terminal end. Still 100 x 100 mm; ERC and DRC clean.
    [control_board.kicad_pcb, control_board.kicad_sch, control_board_bom.csv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]
2026-09-30 Add a bench twin simulator and auto-align, and run the test GUI's sim mode on it (#7)
    tools/bench_twin models the bench: the optics (overlap with the fiber mode
    for single-mode, geometric acceptance for multimode, the 2 mm aperture and
    iris clipping), the motors (100 TPI adjusters, play in the hex couplings,
    crosstalk), the photodiodes through the ADS1115, and knocks. align.py finds
    the light with a spiral on M2, then peaks by steering with M2 and walking
    M1 and M2 together. protocol_bench.py runs the same routine over the
    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
2026-10-02 Add ROS 2 Humble packages for the Jetson (#8)
    Bench driver (status, photodiodes, laser/stop/dark/command services, move_to and align actions; port:=sim runs the bench twin), beam_spot camera node, launch files and udev rule. SerialLink and SimLi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
2026-10-04 Add STEP models of the control board and photodiode amp board (#10)
    STEP exports of electronics/pcb boards for Onshape, in cad/parts/pcb.
    [control_board.step, pd_amp.step]
2026-10-04 Add STEP models of the control and photodiode boards (#11)
    Exported from the KiCad 10 boards in electronics/pcb with component 3D models, plus a 3D render of each. The Feather, TMC2209 and ADS1115 modules, the polyfuse and the BPW34 have no model.
    [control_board.step, pd_amp.step]
2026-10-04 Remove the duplicate PCB STEP files in cad/pcb (#12)
    PR 10 and PR 11 both exported the boards. Keep PR 10's copy in cad/parts/pcb and move PR 11's 3D renders next to it.
    [control_board.step, pd_amp.step]
2026-10-04 Add the full bench assembly STEP and CAD renders (#13)
    Export of the Onshape main assembly with the subassembly tree kept, two renders for the README, and a README in cad/assemblies listing what each subassembly is.
2026-10-10 Animated banner and a new README (#15)
    The README now opens with an animated banner that replays a bench twin knock-and-recover run, and adds figures for the optical path, the code and Auto-align, the PCB renders and a test panel screensh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
